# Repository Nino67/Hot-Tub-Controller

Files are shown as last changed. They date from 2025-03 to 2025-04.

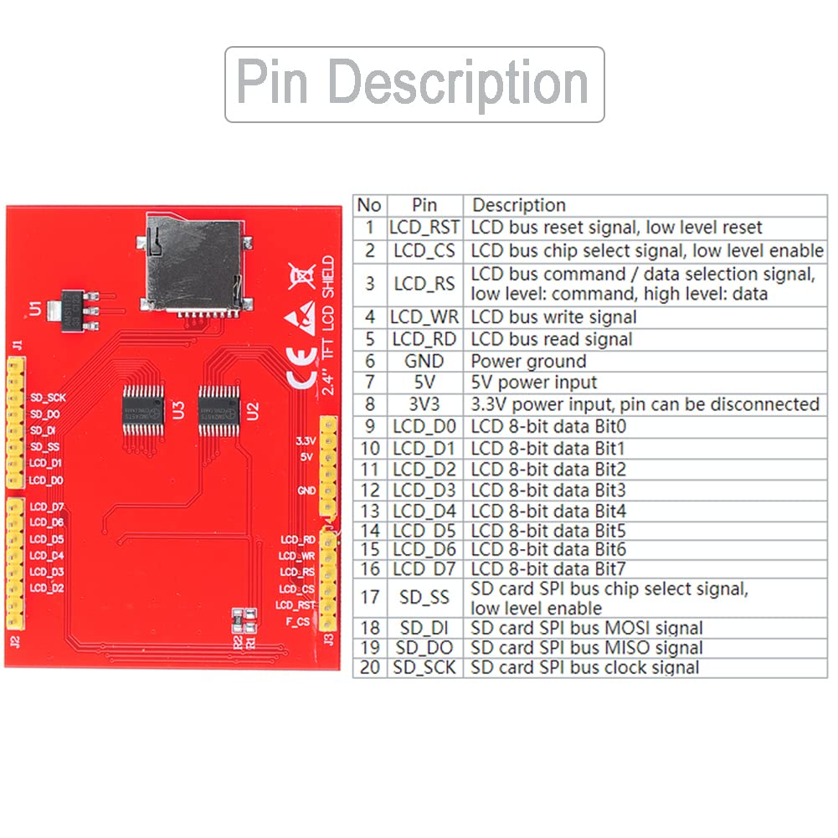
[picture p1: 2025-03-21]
images/TFT_LCD_Display_Module_Pinout.png

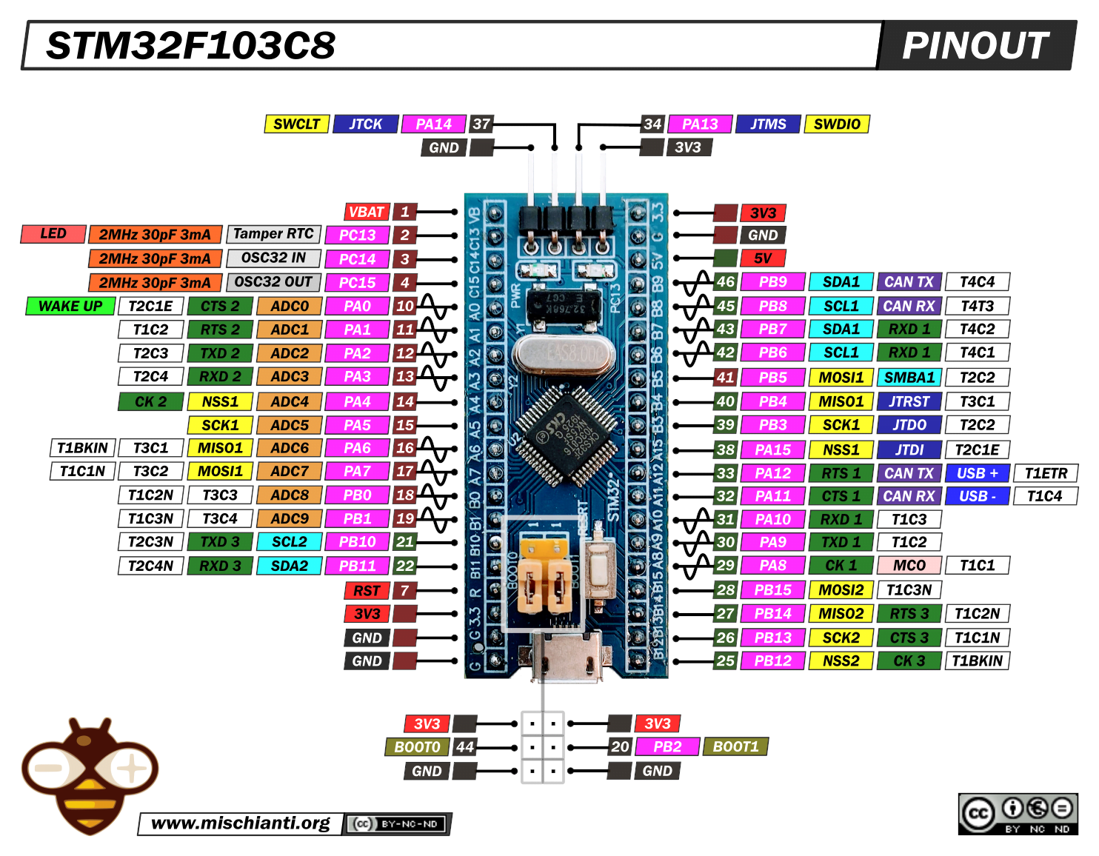
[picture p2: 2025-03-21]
images/stm32_bluepill_pinout.png

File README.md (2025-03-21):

# Hot Tub Controller

## Overview

- This project provides automatic temperature control and auto or manual pump control for a hot tub. It uses an STM32 Blue Pill microcontroller to manage temperature regulation, pump activation, and status communication.

- [Hot Tub Controller Image 1:](images/HotTub-Controller-1.png)
- [Hot Tub Controller Image 2:](images/HotTub-Controller-2.png)

### Description

The Hot Tub Controller utilizes a MAX6675 thermocouple amplifier and K-type thermocouple to monitor the Hot tub temperature. When the heater is enabled and the temperature falls below the setpoint plus the hysteresis value, the controller then checks if the pump is already on and running. If not, it enables the low-speed pump operation before engaging the heater. The system ensures the pump is enabled before heater activation. If the pump was manually enabled by the user the heater deactivation does not deactivate the pump. If pump activation was automatic then pump will turn off at end of heater cycle.

The controller communicates status updates approximately five times a second to a touchscreen display and a Bluetooth module. It allows temperature setting and manual pump control, which when enabled, overrides the automatic pump deactivation during heater cycles.

### Key Features

- **Temperature Monitoring:** Reads temperature using MAX6675 thermocouples.
- **Relay Control:** Controls relays for heater and pump activation.
- **Temperature Regulation:** Implements a basic temperature control algorithm with hysteresis.
- **UART Communication:** Communicates status and receives commands via UART serial ports (Serial, Serial1, Serial2).
- **JSON Messaging:** Handles incoming JSON messages to update hot tub settings.
- **Safety Mechanisms:** Provides temperature range checks to prevent overheating or freezing.
- **Automatic and Manual Pump Control:** Allows for both automatic pump control based on temperature and manual override.

## Hardware Requirements

- **Microcontroller:** STM32 Blue Pill [stm32 bluepill pinout](images/stm32_bluepill_pinout.png) and [stm32f103c8 datasheet](docs/stm32f103c8-1851025.pdf)

- **Thermocouple:** MAX6675 with K-type thermocouple [MAX6675 Module](images/MAX6675-Module-Pinout.png) and [max6675 datasheet](docs/max6675.pdf)

- **Relays:** [4 channel 5v relay module](images/4-channel-5v-relay-module2.png)
  - Relay 1: Heater Control
  - Relay 2: High-Speed Pump Control
  - Relay 3: Low-Speed Pump Control
  - Relay 4: Auxiliary (Specify function)
- **Other Components:**

  - Power Supply [LM2596S Buck Converter](images/LM2596S-Buck-Converter.png)

  - Touchscreen Display [2.4inch TFT LCD Display Module](images/TFT_LCD_Display_Module_and_UNO.png) and [TFT LCD Display Module Pinout](images/TFT_LCD_Display_Module_Pinout.png)

  - Bluetooth Module [HC-06 module](images/HC-06_Bluetooth_Module.png)

### Wiring Diagram

- [Hot Tub Controller Block Wiring Diagram.jpg](images/Hot-Tub-Sch.jpg)

- [Hot Tub Controller Block Wiring Diagram.pdf](docs/Hot-Tub-Sch.pdf)

## Software Requirements

- **Development Environment:** PlatformIO in Visual Studio Code
- **Arduino Libraries:**
  - `SPI` (Included with Arduino framework)
  - `MAX6675` (Adafruit version 1.1.2)
  - `ArduinoJson` (Benoit Blanchon version 6.19.4 )
- **Programming Language:** C++

## Installation and Setup

1.  **Install Visual Studio Code:** Download and install Visual Studio Code from the [official website](https://code.visualstudio.com/).
2.  **Install PlatformIO IDE:** Install the PlatformIO IDE extension in Visual Studio Code.
3.  **Clone the Project:** Clone the project from the repository (if applicable).
    ```git
    git clone https://github.com/Nino67/Hot-Tub-Controller.git
    cd Hot-Tub-Controller
    ```
4.  **Install Arduino Libraries:** PlatformIO will automatically install the required libraries defined in [`platformio.ini`](platformio.ini).
5.  **Configure PlatformIO:**
    - Set the correct board in `platformio.ini`: `board = genericSTM32F103C8`
    - Set the upload port in `platformio.ini` (if necessary): `upload_port = COMx` or `upload_port = /dev/ttyUSB0`
6.  **Upload the Code:** Build and upload the code to the STM32 Blue Pill board using PlatformIO.

## Usage

1.  **Connect the Hardware:** Connect all the hardware components according to the [wiring diagram.](docs/Hot-Tub-Sch.pdf)
2.  **Power On:** Power on the hot tub controller.
3.  **Interact with the Touchscreen Display:** Use the touchscreen display to:
    - Set the target temperature.
    - Enable or disable the heater.
    - Control the pumps (automatic or manual mode).
    - Monitor the status of the hot tub (temperature, pump status, heater status).

### Serial Communication Protocol

The Hot Tub Controller uses JSON messages for communication over the serial ports.

- **BAUDRATE:** `57600 bps` Default settable in [include/globals.h](include/globals.h)

- **Status Updates:** The controller sends status updates in the following JSON format:

  ```json
  {
    "temp": "XX.X",
    "sTemp": XX,
    "heat": true/false,
    "pLo": true/false,
    "pHi": true/false
  }
  ```

  - `temp`: Current temperature in Celsius (formatted to one decimal place).
  - `sTemp`: Set temperature.
  - `heat`: Heater status (true = on, false = off).
  - `pLo`: Low-speed pump status (true = on, false = off).
  - `pHi`: High-speed pump status (true = on, false = off).

- **Commands:** The controller receives commands in the same JSON format. For example, to set the temperature to 100 and enable the heater:

  ```json
  {
    "sTemp": 100,
    "heat": true
  }
  ```

## Project Structure

```
HotTub-2025-05-03/
├── .gitignore             # Specifies intentionally untracked files that Git should ignore
├── LICENSE                # License file (e.g., MIT License)
├── README.md              # Project documentation
├── platformio.ini         # PlatformIO project configuration file
├── src/                   # Source code directory
│   └── main.cpp           # Main application logic
├── include/               # Header files directory
│   └── globals.h          # Global constants, pin assignments, struct definitions
├── lib/                   # (Optional) Directory for custom libraries
├── images/                # Directory for images used in documentation
│   ├── 4-channel-5v-relay-module2.png
│   ├── HC-06_Bluetooth_Module.png
│   ├── Hot-Tub-Sch.jpg    # Block Wiring Diagram
│   ├── LM2596S-Buck-Converter.png
│   ├── MAX6675-Module-Pinout.png
│   ├── stm32_bluepill_pinout.png
│   └── TFT_LCD_Display_Module_and_UNO.png
│   └── TFT_LCD_Display_Module_Pinout.png
├── docs/                  # Directory for datasheets and other documents
│   ├── max6675.pdf        # MAX6675 Datasheet
│   └── stm32f103c8-1851025.pdf  # STM32F103C8 Datasheet
└── .vscode/              # VS Code specific settings (optional)
    └── settings.json      # VS Code settings for the project (e.g., formatting)
```

## Code Structure

- [`main.cpp`](src/main.cpp): Contains the main application logic, including:
  - Initialization of hardware components.
  - Main loop for reading temperature, controlling relays, and communicating status.
  - Functions for handling serial communication and JSON messages.
- [`include/globals.h`](include/globals.h): Defines global constants, pin assignments, and struct definitions.
- [`platformio.ini`](platformio.ini): Contains the PlatformIO project configuration, including board settings, library dependencies, and build flags.

## TODO:

- **PID Based Temperature Control:** Solid State Relays to be added.

## License

Copyright 2025 Nino67\<gricca1967@gmail.com\>

This repository is released under the MIT License, see [LICENSE](./LICENSE).  
Unless attributed otherwise, everything in this repository is under the MIT License.

## Acknowledgments

- ArduinoJson library: [https://arduinojson.org/](https://arduinojson.org/)
- MAX6675 library: [https://github.com/adafruit/MAX6675-library](https://github.com/adafruit/MAX6675-library)

## Contact Information

- Gaetano (Nino) Ricca: [gricca1967@gmail.com](mailto:gricca1967@gmail.com)

## Addendum

- Yes I was forced to build this, blame **Roland**.
- Yes **Roland** does not feed his slaves, or give lunch breaks.
- Mark my words, one day I will get that which is owed, the other half of the sandwhich... heheh

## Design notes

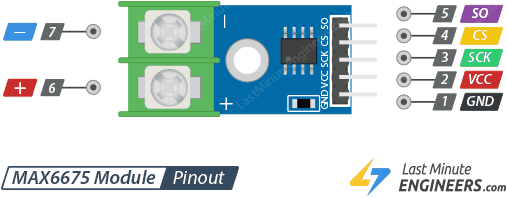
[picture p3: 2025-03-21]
images/MAX6675-Module-Pinout.png

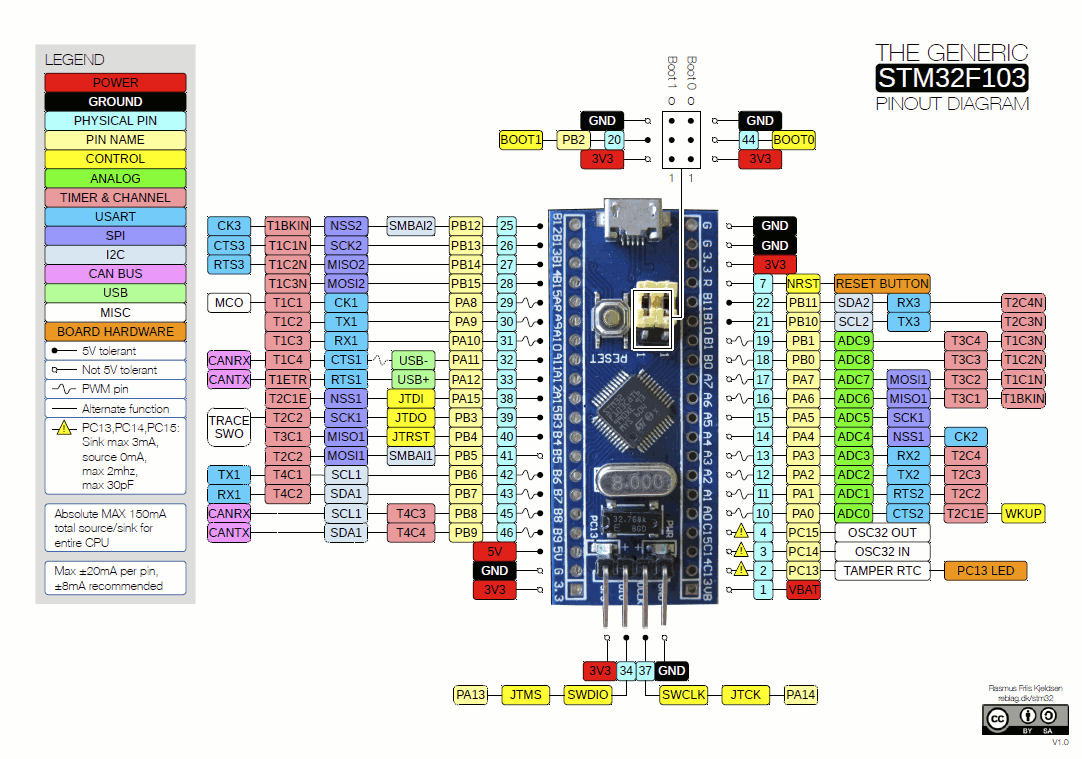
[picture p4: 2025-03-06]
docs/stm32_bluepill_pinout.png

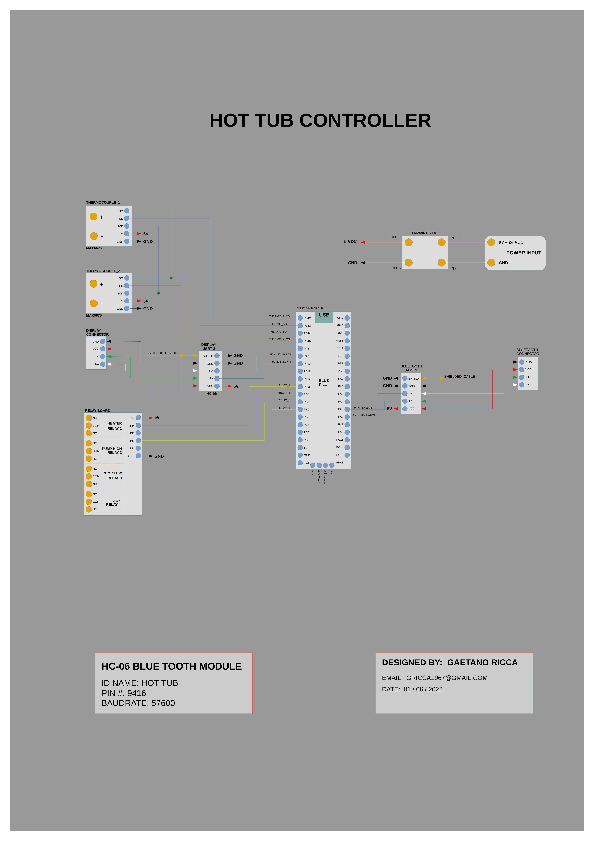
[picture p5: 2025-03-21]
images/Hot-Tub-Sch.jpg

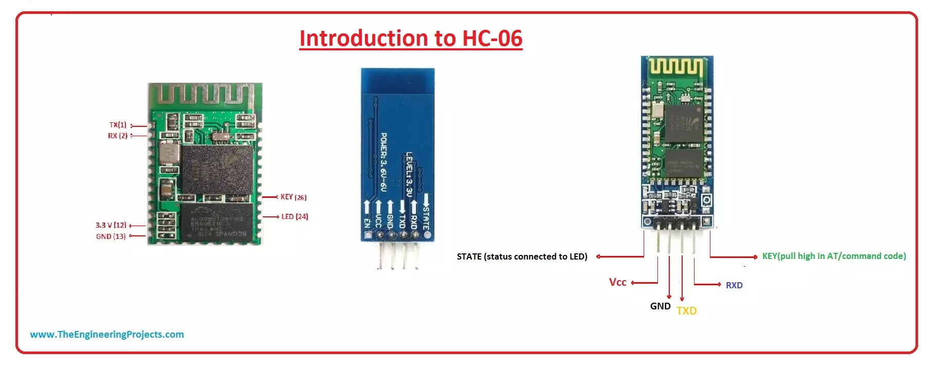
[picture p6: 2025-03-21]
images/HC-06_Bluetooth_Module.png

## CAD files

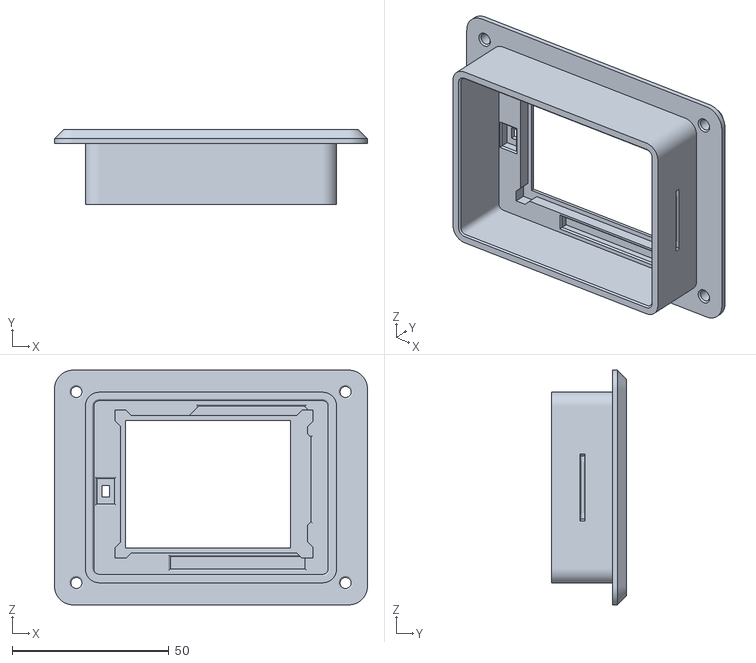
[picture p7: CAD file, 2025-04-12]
stl/Hot tub case stls/cover_plate.stl
100.0 x 24.1 x 75.0

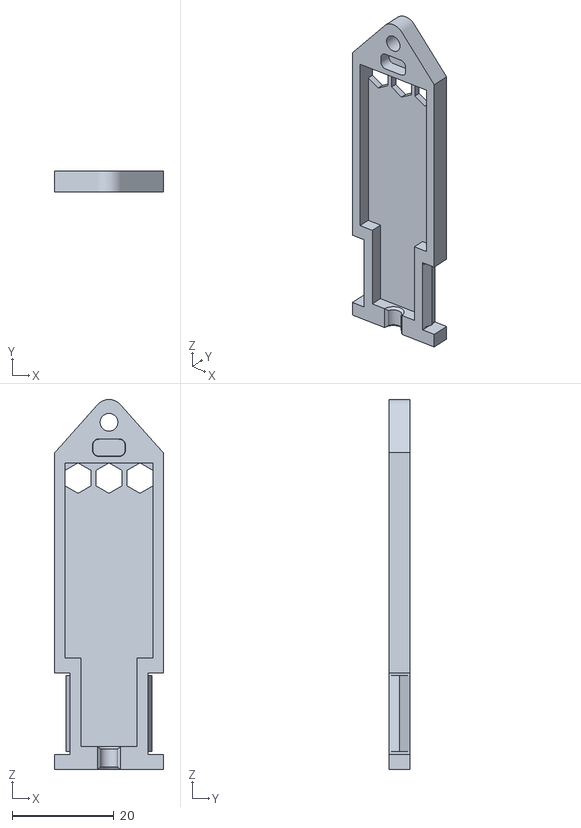
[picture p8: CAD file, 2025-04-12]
stl/Hot tub case stls/Hc-06 case bottom.stl
21.4 x 4.15 x 72.9

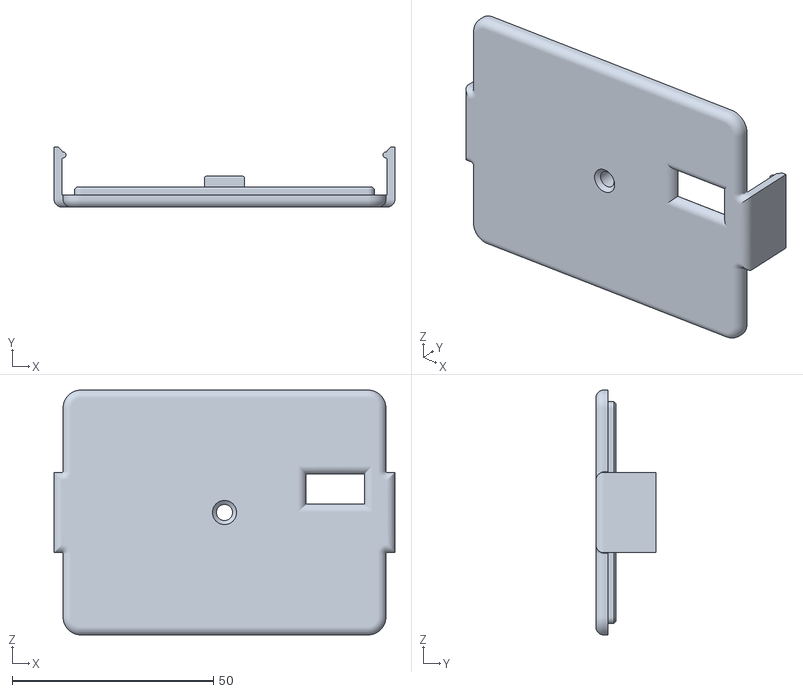
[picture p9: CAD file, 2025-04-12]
stl/Hot tub case stls/base_ plate.stl
84.8 x 15.0 x 60.9

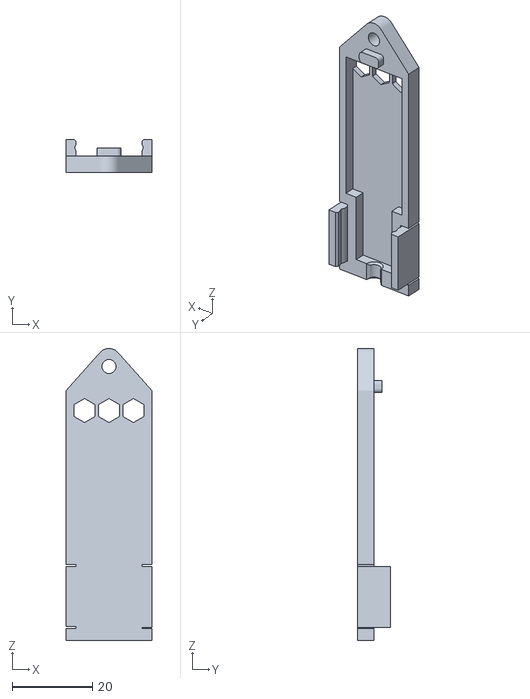
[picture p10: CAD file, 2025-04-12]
stl/Hot tub case stls/HC-06 case top.stl
21.4 x 8.30 x 72.9

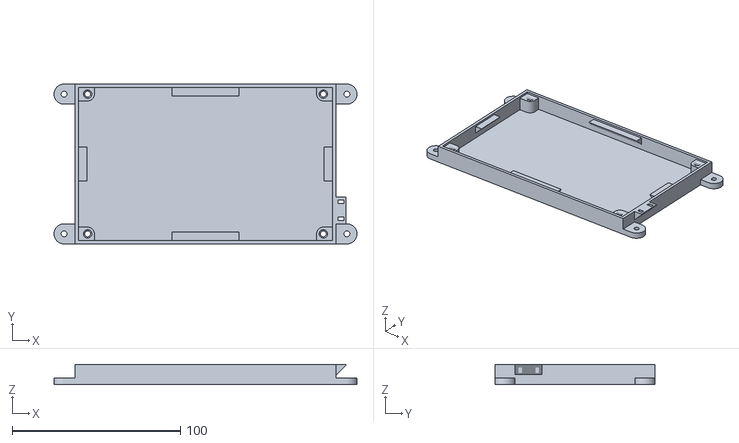
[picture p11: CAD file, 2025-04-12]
stl/Hot tub case stls/Control board mount.stl
180.0 x 95.0 x 12.0

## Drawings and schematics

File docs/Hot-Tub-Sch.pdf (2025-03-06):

# HOT TUB CONTROLLER

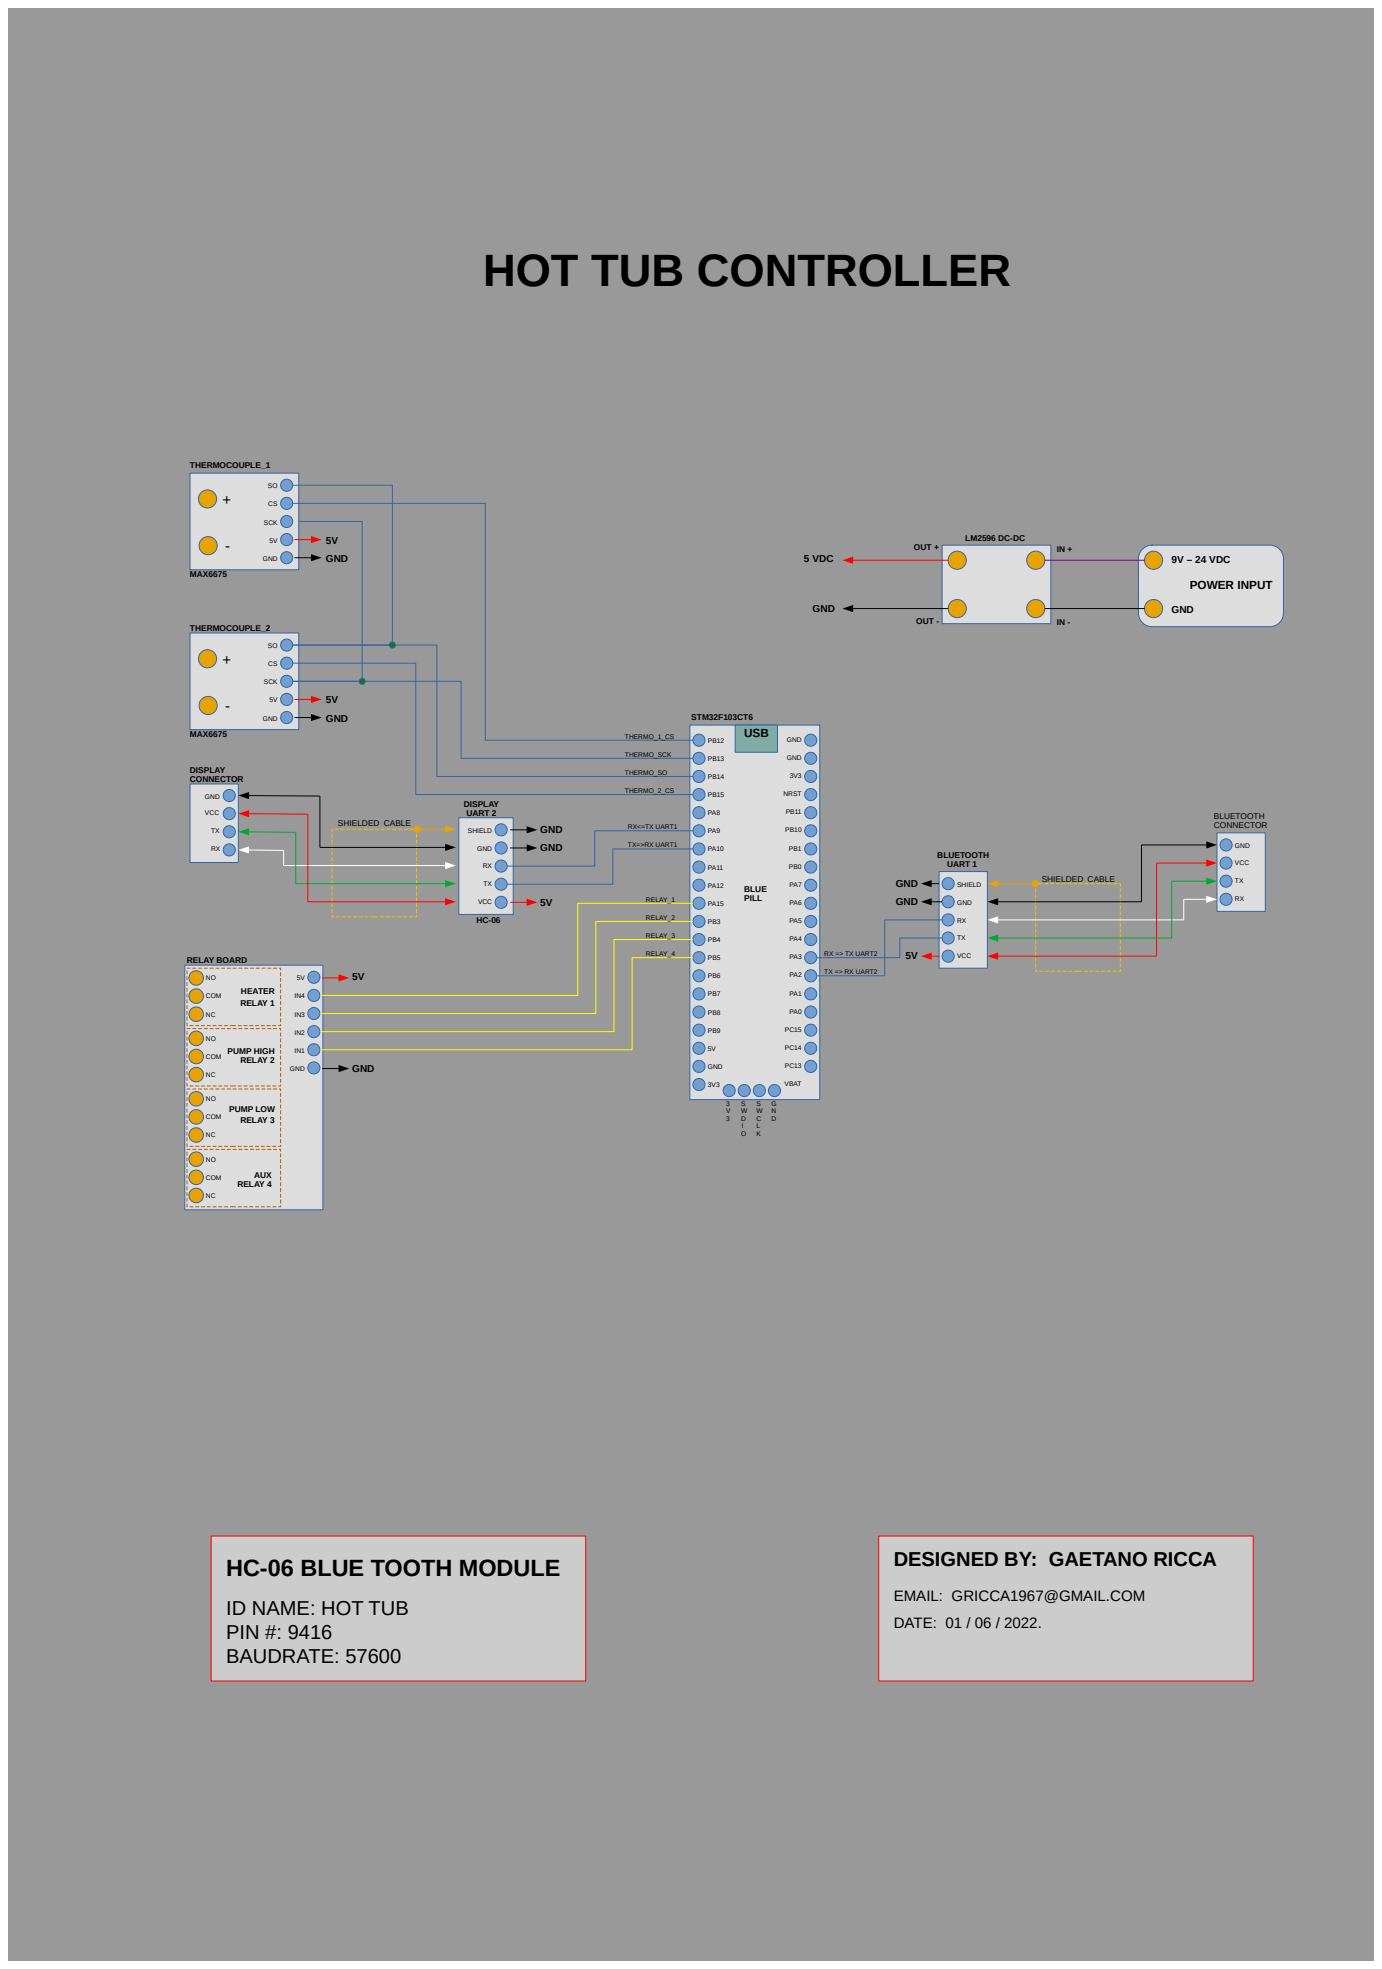
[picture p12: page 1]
GND; NRST; VBAT; USB; COM; RELAY_1; RELAY_2; RELAY_3; RELAY_4; SCK; THERMOCOUPLE_1; THERMOCOUPLE_2; THERMO_1_CS; THERMO_SCK; THERMO_SO; THERMO_2_CS; SHIELD; VCC; RX<=TX UART1; TX=>RX UART1; TX => RX UART2; RX => TX UART2; BLUETOOTH UART 1; DISPLAY UART 2; STM32F103CT6; BLUE PILL; RELAY BOARD; MAX6675; HEATER RELAY 1; PUMP HIGH RELAY 2; PUMP LOW RELAY 3; AUX RELAY 4; OUT +; OUT -; 9V – 24 VDC; 5 VDC; POWER INPUT; SHIELDED CABLE; BLUETOOTH CONNECTOR; DISPLAY CONNECTOR

DESIGNED BY: GAETANO RICCA

HC-06 BLUE TOOTH MODULE
ID NAME: HOT TUB
PIN #: 9416
BAUDRATE: 57600

EMAIL: GRICCA1967@GMAIL.COM
DATE: 01 / 06 / 2022.

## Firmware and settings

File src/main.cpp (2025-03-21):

/**************************************************************************/
/**************************************************************************/
/**
 * @file main.cpp
 * @brief This file contains the main application logic 
 *        for the Hot Tub Controller.
 *
 * @author Gaetano (Nino) Ricca. 
 *                 email gricca1967@gmail.com  
 * @version 1.1.0
 * @date 2021-09-30
 *  
 * The Hot Tub Controller is designed to manage and monitor various 
 * aspects of a hot tub, including temperature regulation, pump control, 
 * and status communication.
 *
 * Key functionalities include:
 *   - Reading temperature from MAX6675 thermocouples.
 *   - Controlling relays for heater and pump activation.
 *   - Implementing a basic temperature control algorithm.
 *   - Communicating status and receiving commands via UART serial ports
 *      (Serial, Serial1, Serial2).
 *   - Handling incoming JSON messages to update hot tub settings.
 *   - Providing safety mechanisms such as temperature range checks.
 *
 * The code is structured with clear function declarations and 
 * comments to facilitate understanding and maintenance. It utilizes 
 * the Arduino framework for STM32 microcontrollers.
 */
/**************************************************************************/
/**************************************************************************/


/**************************************************************************/
/**** Include Files *******************************************************/
/**************************************************************************/
#include "main.h"
/**************************************************************************/


/**************************************************************************/
/**** Function Declarations ***********************************************/
/**************************************************************************/
void setup();
void loop();
void toggleLED(void);
void sendHotTubStatus(void);
void updateHotTubStatus(char*);

void updatePumpStatus(HotTubStruct&);
bool checkSerialForData(HotTubStruct&);
bool checkSerial1ForData(HotTubStruct&);
bool checkSerial2ForData(HotTubStruct&);
bool checkIfHotTubUpdateReceived(HotTubStruct&);
void runBasicTemperatureControl(HotTubStruct&);

void heaterRelayOn(void);           // Relay 1
void heaterRelayOff(void);				  // Relay 1
bool heaterRelayStatus(void);			  // Relay 1
void pumpHighOn(void);					    // Relay 2
void pumpHighOff(void);					    // Relay 2
bool pumpHighStatus(void);				  // Relay 2
void pumpLowOn(void);					      // Relay 3
void pumpLowOff(void);					    // Relay 3
bool pumpLowStatus(void);				    // Relay 3
void Relay4on(void);						    // Relay 4
void Relay4off(void);					      // Relay 4
bool Relay4status (void);				    // Relay 4
void RelaysAllOff(void);
/**************************************************************************/


/**************************************************************************/
/**** Global and Constant Declarations ************************************/
/**************************************************************************/
// Define PID I/O Variables we'll be connecting to
double Setpoint, Input, Output;

// Specify the links and initial PID tuning parameters
double Kp = 2, Ki = 5, Kd = 1;
PID temperaturePID(&Input, &Output, &Setpoint, Kp, Ki, Kd, DIRECT);

// Create an instance of the MAX6675 library
MAX6675 thermocouple1(THERMO_CLK_Pin, THERMO_CS_1_Pin, THERMO_SO_Pin);
MAX6675 thermocouple2(THERMO_CLK_Pin, THERMO_CS_2_Pin, THERMO_SO_Pin);

// Define Serial1 manually (Serial2 is defined in the Arduino framework)
HardwareSerial Serial1(PA10, PA9); // RX, TX for USART1
// HardwareSerial Serial2(PA3, PA2); // RX, TX for USART2

// Initialize Main loop timing variables
static uint32_t currentTime = 0;
static uint32_t lastStatusUpdate = 0;
static uint32_t lastReadUpdate = 0;
/**************************************************************************/


/***************************************************************************/
/**
 * @brief   Function to setup the initial state of the system
 *
 */
void setup()
{
  // Initialize the LED pin as an output
  pinMode(LED_Pin, OUTPUT);

  // Initialize the relay pins as outputs
  pinMode(RELAY_1_Pin, OUTPUT);
  pinMode(RELAY_2_Pin, OUTPUT);
  pinMode(RELAY_3_Pin, OUTPUT);
  pinMode(RELAY_4_Pin, OUTPUT);

  // Set the relay pins to LOW (OFF)
  digitalWrite(RELAY_1_Pin, LOW);
  digitalWrite(RELAY_2_Pin, LOW);
  digitalWrite(RELAY_3_Pin, LOW);
  digitalWrite(RELAY_4_Pin, LOW);


  // Initialize SPI2
  SPI.begin();

  // Initialize UART1
  Serial1.begin(BAUDRATE); // Set the baud rate as needed
  // Initialize UART2
  Serial2.begin(BAUDRATE); // Set the baud rate as needed
  // Initialize USB serial communication for debugging
  Serial.begin(BAUDRATE);

  // delay a second for everything to stabalize
  delay(1000);

} // end of setup() function
/***************************************************************************/


/***************************************************************************/
/**
 * @brief   Main loop function to run the hot tub controller
 *
 */
void loop()
{
  // Reset Main loop timing variables
  currentTime = millis();
  lastStatusUpdate = currentTime;
  lastReadUpdate = lastStatusUpdate;

  // Main endless loop
  while (true) {
    // Get the current time
    currentTime = millis();

    // Check if Status Update time elapsed (default 200ms)
    if ((currentTime - lastStatusUpdate) >= STATUS_UPDATE_TIME) {
      // Check if a update was received before hardware status sent
      checkIfHotTubUpdateReceived(hotTub);
      // Transmit Hot Tub hardware status
      sendHotTubStatus();
      // Update the Hardware status 
      updatePumpStatus(hotTub);
      // Run the basic temperature control algorithm
      runBasicTemperatureControl(hotTub);
      // signal to user that hot tub data packet sent
      toggleLED();
      // Reset the status update loop counter
      lastStatusUpdate = millis();
    } // end of if((currentTime - lastStatusUpdate) >= STATUS_UPDATE_TIME)

    // Check if thermocouple read time elapsed (default 500ms)
    if ((currentTime - lastReadUpdate) >= READ_TIME_DELAY) {
      // Read the temperature from the MAX6675
      hotTub.currentTemp = thermocouple1.readFahrenheit();
      // Reset the thermocouple read loop counter
      lastReadUpdate = millis();
    } // end of if((currentTime - lastReadUpdate) >= READ_TIME_DELAY)
  } // end of while endless loop
} // end of loop() function
/***************************************************************************/


/***************************************************************************/
/**
 * @brief Function to check if a message was received from the hot tub 
 * and update the status accordingly
 * 
 * @param hot_tub   The hot tub struct to store the incoming data
 * @return true   If a message was received
 * @return false  If a message was not received
 */
bool checkIfHotTubUpdateReceived(HotTubStruct &hot_tub)
{
  bool hotTubUpdateReceived = false;

  // Check for incoming data on the USB_UART
  if (checkSerialForData(hot_tub)) {
    updateHotTubStatus((char *)hot_tub.SerialRxMsg);
    // sendHotTubStatus();
    hot_tub.SerialRxMsgLength = 0;
    hot_tub.SerialRxMsgReady = false;
    hotTubUpdateReceived = true;
    return hotTubUpdateReceived;
  } // end of if(checkSerialForData(hot_tub))

  // Check for incoming data on Serial1
  if (checkSerial1ForData(hot_tub)) {
    updateHotTubStatus((char *)hot_tub.Serial1RxMsg);
    // sendHotTubStatus();
    hot_tub.Serial1RxMsgLength = 0;
    hot_tub.Serial1RxMsgReady = false;
    hotTubUpdateReceived = true;
    return hotTubUpdateReceived;
  } // end of if(checkSerial1ForData(hot_tub))

  // Check for incoming data on Serial2
  if (checkSerial2ForData(hot_tub)) {
    updateHotTubStatus((char *)hot_tub.Serial2RxMsg);
    // sendHotTubStatus();
    hot_tub.Serial2RxMsgLength = 0;
    hot_tub.Serial2RxMsgReady = false;
    hotTubUpdateReceived = true;
    return hotTubUpdateReceived;
  } // end of if(checkSerial2ForData(hot_tub))
  return hotTubUpdateReceived;
} // end of checkIfHotTubUpdateReceived() function
/***************************************************************************/


/***************************************************************************/
/**
 * @brief  Function to toggle the LED on the board
 *
 */
void toggleLED()
{
  static bool ledState = LOW;      // Keep track of the LED state
  ledState = !ledState;            // Toggle the state
  digitalWrite(LED_Pin, ledState); // Set the LED to the new state
} // end of toggleLED() function
/***************************************************************************/


/***************************************************************************/
/**
 * @brief Function to send the current hot tub status over UARTS
 *
 */
void sendHotTubStatus()
{
  // Create a JSON object to store the status data
  JsonDocument doc;

  // Buffer to hold the formatted temperature string
  char tempStr[10];

  // Convert float to string with 1 decimal place
  dtostrf(hotTub.currentTemp, 4, 1, tempStr);

  doc["temp"] = tempStr;
  doc["sTemp"] = hotTub.setTemp;
  doc["heat"] = hotTub.HeaterOn;
  doc["pLo"] = hotTub.pumpLowSpeedOn;
  doc["pHi"] = hotTub.pumpHighSpeedOn;

  // Serialize the JSON object to a string
  String output;
  serializeJson(doc, output);

  // Transmit the JSON string over Serial
  Serial.println(output);
  Serial1.println(output);
  Serial2.println(output);
} // end of sendHotTubStatus() function
/***************************************************************************/


/***************************************************************************/
/**
 * @brief  Function to update the hot tub status based on the incoming message
 *
 * @param msg The incoming Json message used to update the hot tub status
 */
void updateHotTubStatus(char *msg)
{
  JsonDocument doc;
  deserializeJson(doc, msg);

  // Check if the temperature is a float
  if (doc["temp"].is<float>()) {
    // Convert the string representation of the float to a float
    float tempValue = doc["temp"].as<float>();
    // Buffer to hold the formatted temperature string
    char tempStr[10];
    // copy the recieved variable to the buffer
    strcpy(tempStr, doc["temp"]);
    // Convert float to string with 1 decimal place
    dtostrf(tempValue, 4, 1, tempStr);
    // Update the hotTub struct with the formatted float value
    hotTub.currentTemp = atof(tempStr);
  }

  // Check if the set temperature is an integer
  if (doc["sTemp"].is<int>()) {
    // Update the hotTub struct with the set temperature
    hotTub.setTemp = doc["sTemp"];
  }

  // Check if the heater status is a boolean
  if (doc["heat"].is<bool>()) {
    // Update the hotTub struct with the heater status
    hotTub.HeaterOn = doc["heat"];
  }

  // Check if the low speed pump status is a boolean
  if (doc["pLo"].is<bool>()) {
    // Update the hotTub struct with the low speed pump status
    hotTub.pumpLowSpeedOn = doc["pLo"];
  }

  // Check if the high speed pump status is a boolean
  if (doc["pHi"].is<bool>()) {
    // Update the hotTub struct with the high speed pump status
    hotTub.pumpHighSpeedOn = doc["pHi"];
  }
} // end of updateHotTubStatus() function
/***************************************************************************/

/**
 * @brief  Function to update the pump status based on the current Hot Tub struct
 * 
 * @param hot_tub   The hot tub struct data to update pump status 
 */
void updatePumpStatus(HotTubStruct &hot_tub) {
  // Check to see if the heater status has changed
  if (hot_tub.pumpLowSpeedOn != pumpLowStatus()) {
    // If the pumpLowSpeedOn is true and the low speed pump relay is off
    if (hot_tub.pumpLowSpeedOn) {
      // Turn off the high speed pump
      pumpHighOff();
      // Turn on the low speed pump
      pumpLowOn();
    } else {
      // Turn off the low speed pump
      pumpLowOff();
    }
  } // end of if(hot_tub.pumpLowSpeedOn != pumpLowStatus())
  
  // Check to see if the high speed pump status has changed
  if (hot_tub.pumpHighSpeedOn != pumpHighStatus()) {
    // If the pumpHighSpeedOn is true and the high speed pump relay is off
    if (hot_tub.pumpHighSpeedOn) {
      // Turn off the low speed pump
      pumpLowOff();
      // Turn on the high speed pump  
      pumpHighOn();
    } else {
      // Turn off the high speed pump
      pumpHighOff();
    } // end of if(hot_tub.pumpHighSpeedOn != pumpHighStatus())
  } // end of if(hot_tub.pumpHighSpeedOn != pumpHighStatus())
} // end of updatePumpStatus() function
/***************************************************************************/


/***************************************************************************/
/**
 * @brief runBasicTemperatureControl()
 * @param hot_Tub   The hot tub struct to store the incoming data
 * @retval None
 */
void runBasicTemperatureControl(HotTubStruct &hot_tub)
{
  // If temperature reading is out of range set heater off and return (safety check)
  if((hot_tub.currentTemp > MIN_ALLOWED_TEMP) && (hot_tub.currentTemp < MAX_ALLOWED_TEMP))
  {
    
    // Check if the user requested the heater on
    if (hot_tub.HeaterOn) 
    {
      // Check to see if temperature is above the user setpoint
      if(hot_tub.currentTemp > hot_tub.setTemp)
      {
        // Set belowSetpoint flag to false to indicate above setpoint
        hot_tub.belowSetpoint = false;
        // Turn off the heater relay
        heaterRelayOff();
        // Check if pump is under user control if not turn off the low speed pump
        if (!(hot_tub.pumpHighSpeedOn || hot_tub.pumpLowSpeedOn))
        {
          // Turn off the low speed pump under heater control
          pumpLowOff();
        } // end of if(!(hot_tub.pumpHighSpeedOn || hot_tub.pumpLowSpeedOn))
      } // end of if(hot_tub.currentTemp > hot_tub.setTemp)
      
      // Check to see if temperature is below (setpoint - hysterisis) 
      // if yes set flag for heater turn on
      if(hot_tub.currentTemp < (hot_tub.setTemp - hot_tub.hysterisis))
      {
        // Set belowSetpoint flag to true
        hotTub.belowSetpoint = true;
      } // end of if(hot_tub.currentTemp < (hot_tub.setTemp - hot_tub.hysterisis))

      // Check to see if belowSetpoint is true and temperature is below setpoint - hysterisis
      if(hot_tub.belowSetpoint && (hot_tub.currentTemp < (hot_tub.setTemp - hot_tub.hysterisis)))
      {
        if(hot_tub.pumpHighSpeedOn || hot_tub.pumpLowSpeedOn) 
        {
          // Check if the high speed pump is on
          if(hot_tub.pumpHighSpeedOn)
          {
            // Turn on the high speed pump
            pumpHighOn();
          }
          else
          {
            // Turn on the low speed pump
            pumpLowOn();
          } // end of if(hot_tub.pumpHighSpeedOn)
          // Turn on the heater relay
          heaterRelayOn();
        }
        else 
        {
          // Turn on the low speed pump
          pumpLowOn();
          // Turn on the heater relay
          heaterRelayOn();
        } // end of if(hot_tub.pumpHighSpeedOn || hot_tub.pumpLowSpeedOn)
      } // end of if(hot_tub.belowSetpoint && (hot_tub.currentTemp < (hot_tub.setTemp - hot_tub.hysterisis)))
    } // end of if (hot_tub.HeaterOn) 
  }
  else
  {
	  // Out of range temperature shut down heater and return
	  hot_tub.HeaterOn = false;
	  heaterRelayOff();
  }
} // end of runBasicTemperatureControl() function
/***************************************************************************/


/***************************************************************************/
/**
 * @brief Function to check for incoming serial data on USB_UART
 *
 * @param hot_tub  The hot tub struct to store the incoming data
 * @return true  If a message is ready
 * @return false  If a message is not ready
 */
bool checkSerialForData(HotTubStruct &hot_tub)
{
  while (Serial.available() > 0)
  {
    char c = Serial.read();
    if (hot_tub.SerialRxMsgLength < MAX_BUFFER_SIZE)
    {
      hot_tub.SerialRxMsg[hot_tub.SerialRxMsgLength++] = c;
    }
    else
    {
      // Handle overflow, reset the buffer, flush the uart and reset msg flag
      Serial.flush();
      hot_tub.SerialRxMsgLength = 0;
      hot_tub.SerialRxMsgReady = false;
    }
    // Check for the end of the message (newline character)
    if (c == '\n')
    {
      hot_tub.SerialRxMsgReady = true;
      break;
    }
  } // end of while loop
  return hot_tub.SerialRxMsgReady;
} // end of checkSerialForData() function
/***************************************************************************/


/***************************************************************************/
/**
 * @brief   Function to check for incoming serial data on Serial1
 * 
 * @param hot_tub   The hot tub struct to store the incoming data
 * @return true   If a message is ready 
 * @return false  If a message is not ready
 */
bool checkSerial1ForData(HotTubStruct &hot_tub)
{
  while (Serial1.available() > 0)
  {
    char c = Serial1.read();
    if (hot_tub.Serial1RxMsgLength < MAX_BUFFER_SIZE)
    {
      hot_tub.Serial1RxMsg[hot_tub.Serial1RxMsgLength++] = c;
    }
    else
    {
      // Handle overflow, reset the buffer, flush the uart and reset msg flag
      Serial1.flush();
      hot_tub.Serial1RxMsgLength = 0;
      hot_tub.Serial1RxMsgReady = false;
    }
    // Check for the end of the message (newline character)
    if (c == '\n')
    {
      hot_tub.Serial1RxMsgReady = true;
      break;
    }
  } // end of while loop
  return hot_tub.Serial1RxMsgReady;
} // end of checkSerial1ForData() function
/***************************************************************************/


/***************************************************************************/
/**
 * @brief  Function to check for incoming serial data on Serial2
 *
 * @param hot_tub The hot tub struct to store the incoming data
 * @return true If a message is ready
 * @return false  If a message is not ready
 */
bool checkSerial2ForData(HotTubStruct &hot_tub)
{
  while (Serial2.available() > 0)
  {
    char c = Serial2.read();
    if (hot_tub.Serial2RxMsgLength < MAX_BUFFER_SIZE)
    {
      hot_tub.Serial2RxMsg[hot_tub.Serial2RxMsgLength++] = c;
    }
    else
    {
      // Handle overflow, reset the buffer, flush the uart and reset msg flag
      Serial2.flush();
      hot_tub.Serial2RxMsgLength = 0;
      hot_tub.Serial2RxMsgReady = false;
    }
    // Check for the end of the message (newline character)
    if (c == '\n')
    {
      hot_tub.Serial2RxMsgReady = true;
      break;
    }
  } // end of while loop
  return hot_tub.Serial2RxMsgReady;
} // end of checkSerial2ForData() function
/***************************************************************************/


/**
 * @brief   Function to turn on the heater relay
 * 
 */
void heaterRelayOn(void) {
  digitalWrite(RELAY_1_Pin, HIGH);
} // end of heaterRelayOn() function
/**************************************************************************/


/**************************************************************************/
/**
 * @brief   Function to turn off the heater relay
 * 
 */
void heaterRelayOff(void) {
  digitalWrite(RELAY_1_Pin, LOW);
}  
/**************************************************************************/


/**************************************************************************/
/**
 * @brief  Function to check the status of the heater relay
 * 
 * @return true  If the relay is on  
 * @return false If the relay is off
 */
bool heaterRelayStatus(void) {
  return digitalRead(RELAY_1_Pin) == HIGH;
} // end of heaterRelayStatus() function
/**************************************************************************/


/**************************************************************************/
/**
 * @brief   Function to turn on the high speed pump relay
 * 
 */
void pumpHighOn(void) {
  digitalWrite(RELAY_2_Pin, HIGH);
} // end of pumpHighOn() function
/**************************************************************************/


/**************************************************************************/
/**
 * @brief   Function to turn off the high speed pump relay
 * 
 */
void pumpHighOff(void) {
  digitalWrite(RELAY_2_Pin, LOW);
} // end of pumpHighOff() function
/**************************************************************************/


/**************************************************************************/
/**
 * @brief   Function to check the status of the high speed pump relay
 * 
 * @return true   If the relay is on
 * @return false  If the relay is off
 */
bool pumpHighStatus(void) {
  return digitalRead(RELAY_2_Pin) == HIGH;
} // end of pumpHighStatus() function  
/**************************************************************************/


/**************************************************************************/
/**
 * @brief   Function to turn on the low speed pump relay
 * 
 */
void pumpLowOn(void) {
  digitalWrite(RELAY_3_Pin, HIGH);
} // end of pumpLowOn() function
/**************************************************************************/


/**************************************************************************/
/**
 * @brief   Function to turn off the low speed pump relay
 * 
 */
void pumpLowOff(void) {
  digitalWrite(RELAY_3_Pin, LOW);
} // end of pumpLowOff() function
/**************************************************************************/


/**************************************************************************/
/**
 * @brief   Function to check the status of the low speed pump relay
 * 
 * @return true   If the relay is on
 * @return false  If the relay is off
 */
bool pumpLowStatus(void) {
  return digitalRead(RELAY_3_Pin) == HIGH;
} // end of pumpLowStatus() function
/**************************************************************************/
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

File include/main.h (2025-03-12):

#include "globals.h"
#include <SPI.h>
#include <max6675.h>
#include <ArduinoJson.h>
#include <pid.h>

// Hot Tub Min and Max Temperature range
#define MAX_ALLOWED_TEMP 45
#define MIN_ALLOWED_TEMP 0
#define HYSTERISIS 3

// Timing Constants
#define START_UP_DELAY 3500
#define READ_TIME_DELAY 500
#define STATUS_UPDATE_TIME 200

// Buffer Size for UART
#define MAX_BUFFER_SIZE 200

// Hot Tub Structure Definition
static struct HotTubStruct {
  // Hot Tub Variables
  float currentTemp = 20;
  float setTemp = 20;
  float airTemp = 0;
  bool HeaterOn = false;
  bool pumpLowSpeedOn = false;
  bool pumpHighSpeedOn = false;

  // Serial USB Variables
  uint8_t SerialTxMsg[MAX_BUFFER_SIZE];
  uint8_t SerialRxMsg[MAX_BUFFER_SIZE];
  int SerialTxMsgLength = 0;
  int SerialRxMsgLength = 0;
  bool SerialTxMsgReady = false;
  bool SerialRxMsgReady = false;
  
    // Serial1 Variables
  uint8_t Serial1TxMsg[MAX_BUFFER_SIZE];
  uint8_t Serial1RxMsg[MAX_BUFFER_SIZE];
  int Serial1TxMsgLength = 0;
  int Serial1RxMsgLength = 0;
  bool Serial1TxMsgReady = false;
  bool Serial1RxMsgReady = false;
  
  // Serial2 Variables
  uint8_t Serial2TxMsg[MAX_BUFFER_SIZE];
  uint8_t Serial2RxMsg[MAX_BUFFER_SIZE];
  int Serial2TxMsgLength = 0;
  int Serial2RxMsgLength = 0;
  bool Serial2TxMsgReady = false;
  bool Serial2RxMsgReady = false;

  // Variable to signify temperature went below setpoint
  bool belowSetpoint = true;
  // Variable to signify temperature range window below setpoint
  int hysterisis = HYSTERISIS;
} hotTub;

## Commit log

2025-03-06 basic framework setup, thermocouple and 3 serial ports working. Initial Start Up.
2025-04-12 Updated main.cpp with new logic and README.md with project structure and stl's
    [Control board mount.stl, HC-06 case top.stl, Hc-06 case bottom.stl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]
